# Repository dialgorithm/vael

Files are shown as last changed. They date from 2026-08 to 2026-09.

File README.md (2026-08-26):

<h1 align="center">
  vael
  <br>
</h1>

<h4 align="center">
esp32-s3 n8r8 flight controller for sensing and data logging.
</h4>

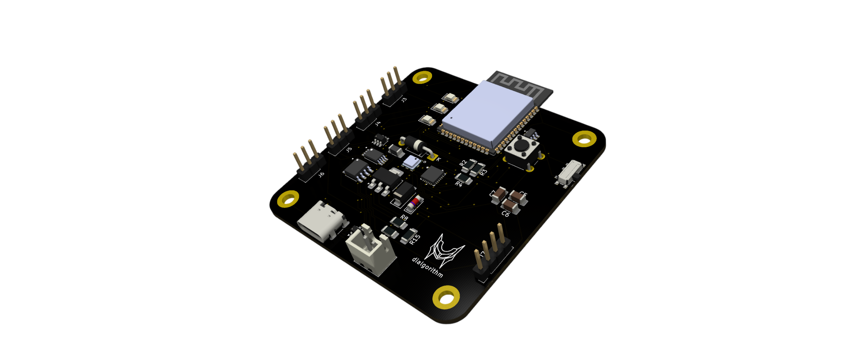
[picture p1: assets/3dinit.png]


## it features

- **ESP32-S3-WROOM-1-N8R8** as the main controller
- **MPU6050** 3-axis accelerometer and gyroscope for motion and orientation data
- **BMP180** digital pressure sensor for pressure and altitude-related measurements
- **MicroSD card storage** for flight data logging
- **USB-C connectivity** for programming, debugging, and data transfer
- **TP4056-based LiPo charging** circuitry
- **DW01A battery protection** for LiPo protection
- **MT3608 boost converter** for generating the required higher-voltage rail
- **AMS1117-3.3 LDO** for regulated 3.3 V power
- **USBLC6-2SC6 ESD protection** for USB protection

## design

**vael** is designed to keep the electronics compact while providing enough space for sensors, power circuitry, storage, and connectivity.

the board is built around the **esp32-s3-wroom-1-n8r8**, with the supporting electronics integrated onto a custom pcb. it combines the **imu, pressure sensor, microsd storage, usb-c interface, battery charging, protection, and voltage regulation** into a single compact board.

the layout keeps the sensing and processing electronics centralized while separating the power and signal sections. the **mpu6050** and **bmp180** are positioned for consistent sensor measurements, while the **microsd slot, usb-c connector, battery connector, reset button, and mode switch** are accessible from the board edges.

the board primarily uses **smd components**, including 1206 passives and compact sensor packages, to maintain a small form factor while providing the hardware required for **data collection, logging, and embedded flight applications**.

## Schematics + PCB

| Schematic | PCB | 3d |
| --- | --- | --- |
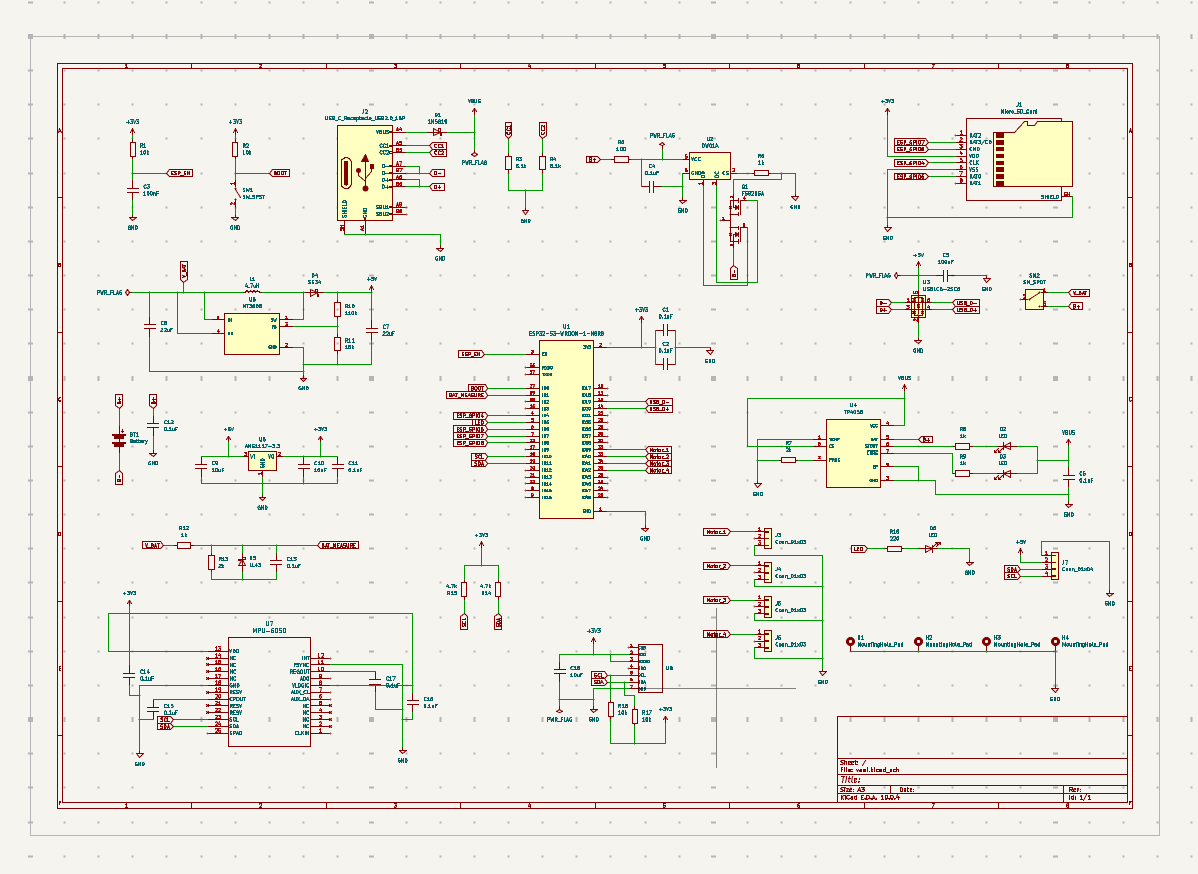
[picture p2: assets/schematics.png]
schematic
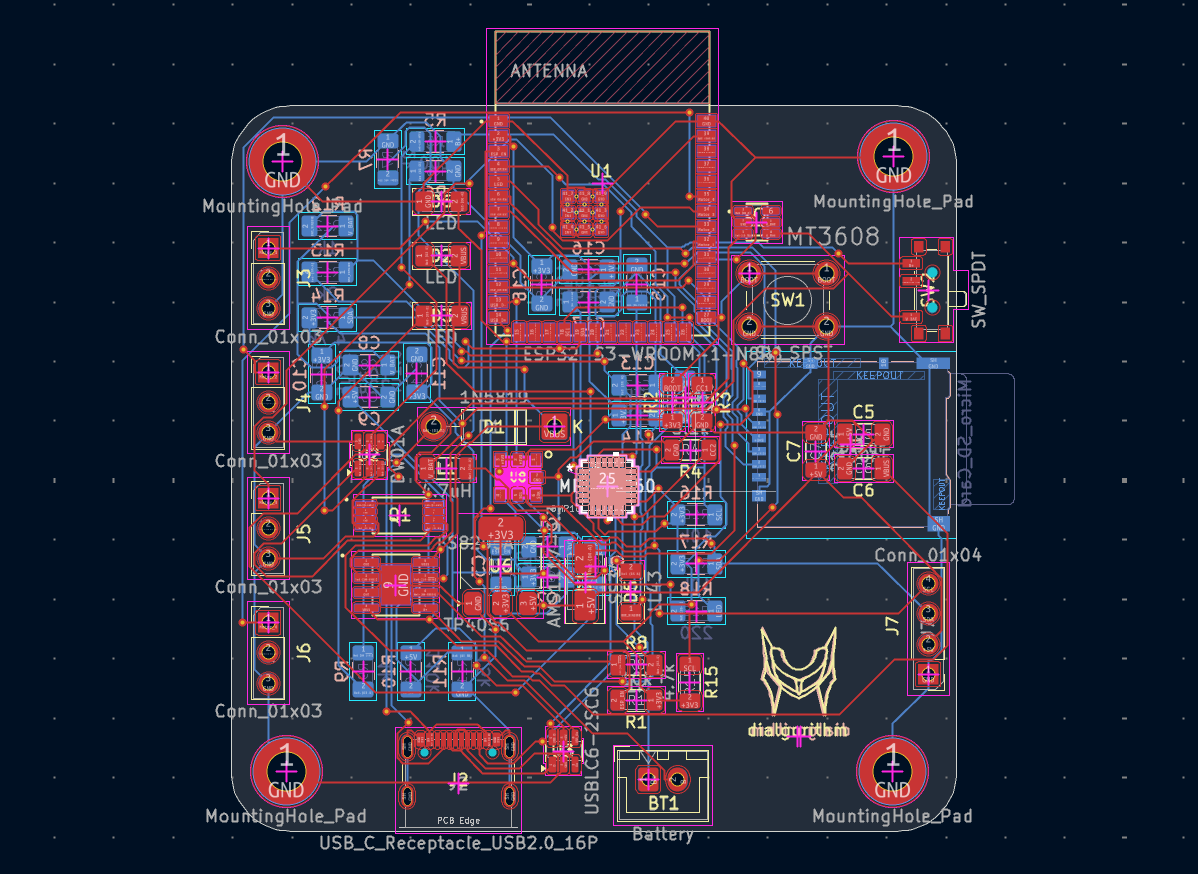
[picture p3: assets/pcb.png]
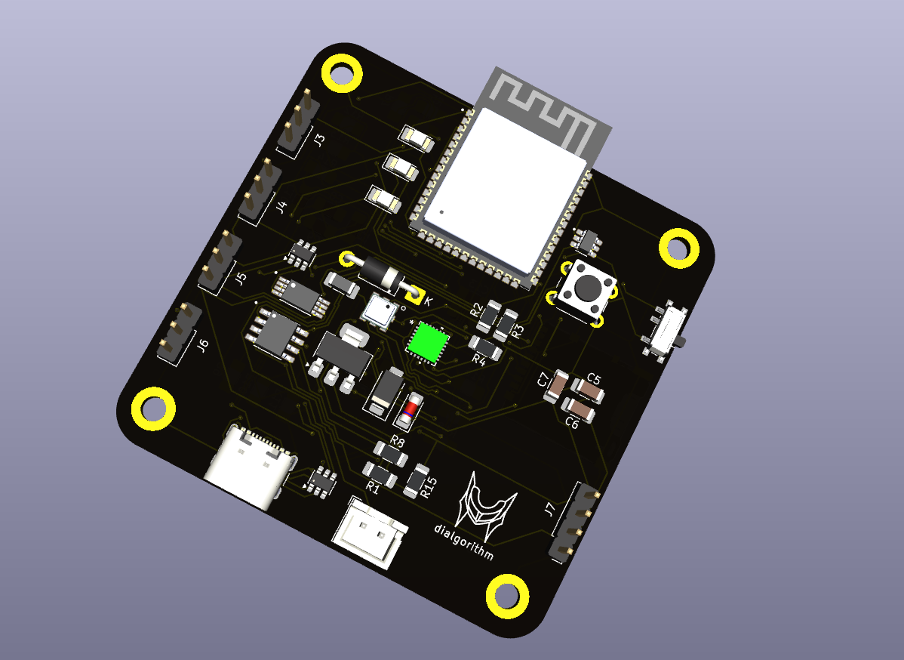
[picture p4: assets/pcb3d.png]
|  |  |  |

## BOM

the complete bill of materials is available in [`bom.csv`](bom.csv).

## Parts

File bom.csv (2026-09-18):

component | qty | cost | why | source
pcb | 5 | $13 | main | https://robu.in/product/online-pcb-manufacturing-service/
JST XH Pitch Plug and Socket | 2 | $0.5 | connect battery | https://robu.in/product/2-pin-jst-xh-2-54mm-pitch-plug-and-socket-with-cable-10-pcs/
0.1uF 1206 Capacitor | 22 | $1 | 11 per pcb | https://robu.in/product/0-1uf-capacitor-smdc-1206/
10uF 1206 Capacitor | 6 | $1.3 | 3 per pcb | https://robu.in/product/10uf-10000nf-50v-capacitor-1206-smd-package-pack-of-5/
100nF 1206 Capacitor | 5 | $0.5 | 2 per pcb | https://robu.in/product/100nf-1206-surface-mount-multilayer-ceramic-capacitor-pack-of-30/
22uF 1206 Capacitor | 5 | $0.5 | 2 per pcb | https://robu.in/product/1206x226m250nt-fh-25v-22uf-x5r%c2%b120-1206-multilayer-ceramic-capacitors-mlcc-smd-smt-rohs/
1N5819 Schottky Diodes | 2 | $0.9 | one way current flow | https://robu.in/product/1-month-warranty-1053/
LED 1206 Package | 6 | $0.8 | 3 per pcb | https://robu.in/product/xl-3216uoc-fb-xinglight-reverse-mount-orange-120-1206-led-indication-discrete-rohs/
SS34 Schottky Diodes ROHS | 2 | $2.3 | non reversible current | https://robu.in/product/ss34-onsemi-40v-500mv3a-3a-smcdo-214ab-schottky-diodes-rohs/
LL43-GS08 Rectifier Diode | 2 | $3 | no current backflow | https://www.lioncircuits.com/parts/LL43-GS08
DM3AT-SF-PEJM5 Micro SD socket | 2 | $13 | flight logs | https://www.lioncircuits.com/parts/DM3AT-SF-PEJM5
GCT USB4105 (USB C) Connector | 2 | $4 | flash and debug | https://www.lioncircuits.com/parts/USB4105-GF-A
2.54mm Male pin header | 10 | $3 | for motor connections | https://robu.in/product/2-54mm-1x40-pin-male-single-row-straight-short-header-strip-pack-of-3/
4.7uH 120p6 Inductor | 2 | $2.2 | for impedance | https://robu.in/product/lqm31pn4r7m00l-murata-electronics-700ma-4-7uh-%c2%b120-375m%cf%89-1206-inductors-smd-rohs/
FS8205A Mosfets | 5 | $1 |  | https://robu.in/product/1-month-warranty-398/
10k 1206 Resistors | 8 | $1 | 4 per pcb | https://robu.in/product/rc1206fr-0710kl-yageo-res-thick-film-1206-10k-ohm-1-0-25w1-4w-%c2%b1100ppm-c-pad-smd-t-r/
110k 1206 Resistors | 5 | $1 | resist current | https://robu.in/product/1206w4f1103t5e-uniohm-royal-ohm-250mw-thick-film-resistors-200v-%c2%b1100ppm-%e2%84%83%c2%b11-110k%cf%89-1206-chip-resistor-surface-mo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
15k 1206 Resistors | 5 | $1 | resist current | https://robu.in/product/1206w4f1502t5e-uniohm-royal-ohm-250mw-thick-film-resistors-200v-%c2%b1100ppm-%e2%84%83-%c2%b11-15k%cf%89-1206-chip-resistor-surface-mo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
1k 1206 Resistors | 8 | $1 | 4 per pcb | https://robu.in/product/wr12x1001ftl-walsin-250mw-thick-film-resistors-200v-%c2%b1100ppm-%e2%84%83-%c2%b11-1k%cf%89-1206-chip-resistor-surface-mount-rohs/
2k 1206 Resistors | 4 | $1 | 2 per pcb | https://robu.in/product/wr12x2001ftl-walsin-250mw-thick-film-resistors-200v-%c2%b1100ppm-%e2%84%83-%c2%b11-2k%cf%89-1206-chip-resistor-surface-mount-rohs/
4.7k 1206 Resistors | 4 | $1 | 2 per pcb | https://robu.in/product/rc1206fr-104k7l-yageo-250mw-thick-film-resistors-%c2%b1100ppm-%e2%84%83-%c2%b11-4-7k%cf%89-1206-chip-resistor-surface-mount-rohs/
220 1206 Resistors | 5 | $1 | resist current | https://robu.in/product/1206w4f2200t5e-uniohm-royal-ohm-250mw-thick-film-resistors-200v-%c2%b1100ppm-%e2%84%83%c2%b11-220%cf%89-1206-chip-resistor-surface-mou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
5.1k 1206 Resistors | 4 | $1 | 2 per pcb | https://robu.in/product/1206w4f5101t5e-uniohm-royal-ohm-250mw-thick-film-resistors-200v-%c2%b1100ppm-%e2%84%83-%c2%b11-5-1k%cf%89-1206-chip-resistor-surface-m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
100 1206 Resistors | 5 | $1 | resist current | https://robu.in/product/ac1206fr-07100rl-yageo-res-thick-film-1206-100-ohm-1-0-25w1-4w-%c2%b1100ppm-c-pad-smd-t-r-automotive-aec-q200/
6x6x5mm Tactile Push Button Switch | 2 | $1 | reset clicky | https://robu.in/product/6x6x5mm-tactile-push-button-switch-pack-of-20/
Mini Slide Switch 7Pin SMD | 2 | $1 | mode slide switch | https://sharvielectronics.com/product/mini-slide-switch-7pin-smd-2-positions-h1-5mm-1p2t-spdt/
ESP32-S3-WROOM-1-N8R8 | 2 | $13.8 | brain | https://robu.in/product/espressif-esp32-s3-wroom-1-n8r8-modules/
DW01A Battery Protection IC | 2 | $1 | protect pcb | https://robu.in/product/dw01a-4-3v-lithium-ion-lithium-polymer-battery-protection-ic-6pin-sot-23/
USBLC6-2SC6 ESD and Surge Protection IC | 2 | $1 | protect pcb | https://robu.in/product/usblc6-2sc6-ms-msksemi-4-5a-15v-150w-6v-5v-sot-23-6-esd-and-surge-protection-tvs-esd-rohs/
TP4056 SOP-8 SMD Package | 2 | $1 | battery charging | https://robu.in/product/1-month-warranty-1253/
MT3608 DC Boost converter | 2 | $1 | 3.3v ==> 5v | https://robu.in/product/mt3608-xian-aerosemi-tech-boost-type-adjustable-2a-2v24v-sot-23-6-dc-dc-converters-rohs/
AMS1117-3.3 LDO Regulators | 2 | $1 | regulates voltage | https://robu.in/product/1-month-warranty-385/
MPU 6050 QFN-24 3-Axis Gyro/Accelerometer IC | 2 | $11.6 | orientation and position data | https://zbotic.in/product/mpu-6050-qfn-24-3-axis-gyro-accelerometer-ic/
BMP180 LGA-7 Digital Pressure Sensor IC | 2 | $5.2 | pressure data | https://sharvielectronics.com/product/bmp180-digital-pressure-sensor-ic-lga-7-package/
8GB MicroSD Card | 2 | $8.4 | data logging | https://sharvielectronics.com/product/8gb-memory-card-sandisk/
Total | - | $110 | - | -

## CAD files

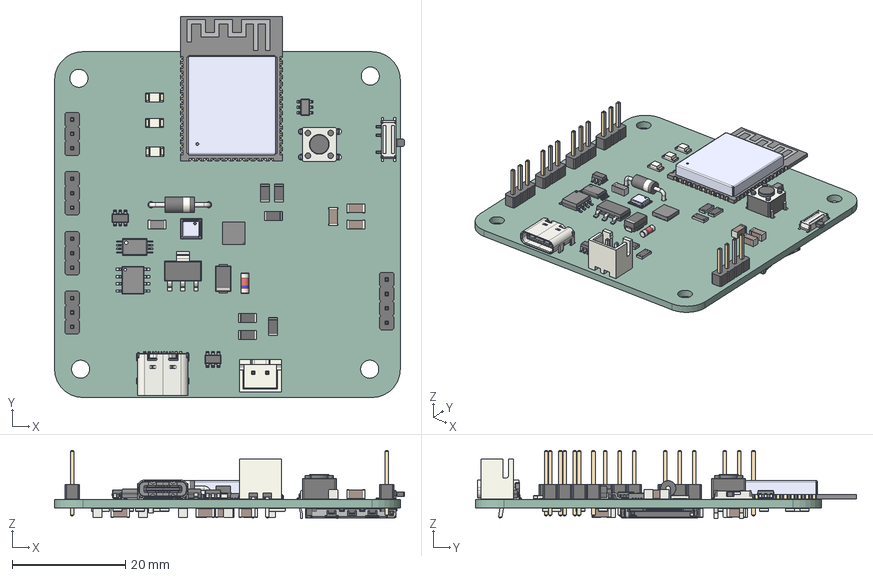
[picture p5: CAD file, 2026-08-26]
KiCAD/vael.step
61.7 x 67.2 x 12.0 mm
MT3608
ICM-20689
R_1206_3216Metric x 18
D_SMA
C_1206_3216Metric x 18
D_DO-41_SOD81_P10.16mm_Horizontal
SOT-223
LED_1206_3216Metric x 3
BMP180
JST_B2B_XH_A
SOT-23-6 x 2
PinHeader_1x04_P254mm_Vertical
ESP32-S3-WROOM-1-N8R2
FS8205A
L_1206_3216Metric
SW_PUSH_6mm
D_MiniMELF_Standard
TP4056
PinHeader_1x03_P254mm_Vertical x 4
Fusion_sp
USB_C_Receptacle_16P_TopMnt_Horizontal_GCT_USB4105-xx-A
microSD_HC_Hirose_DM3AT-SF-PEJM5
vael_PCB

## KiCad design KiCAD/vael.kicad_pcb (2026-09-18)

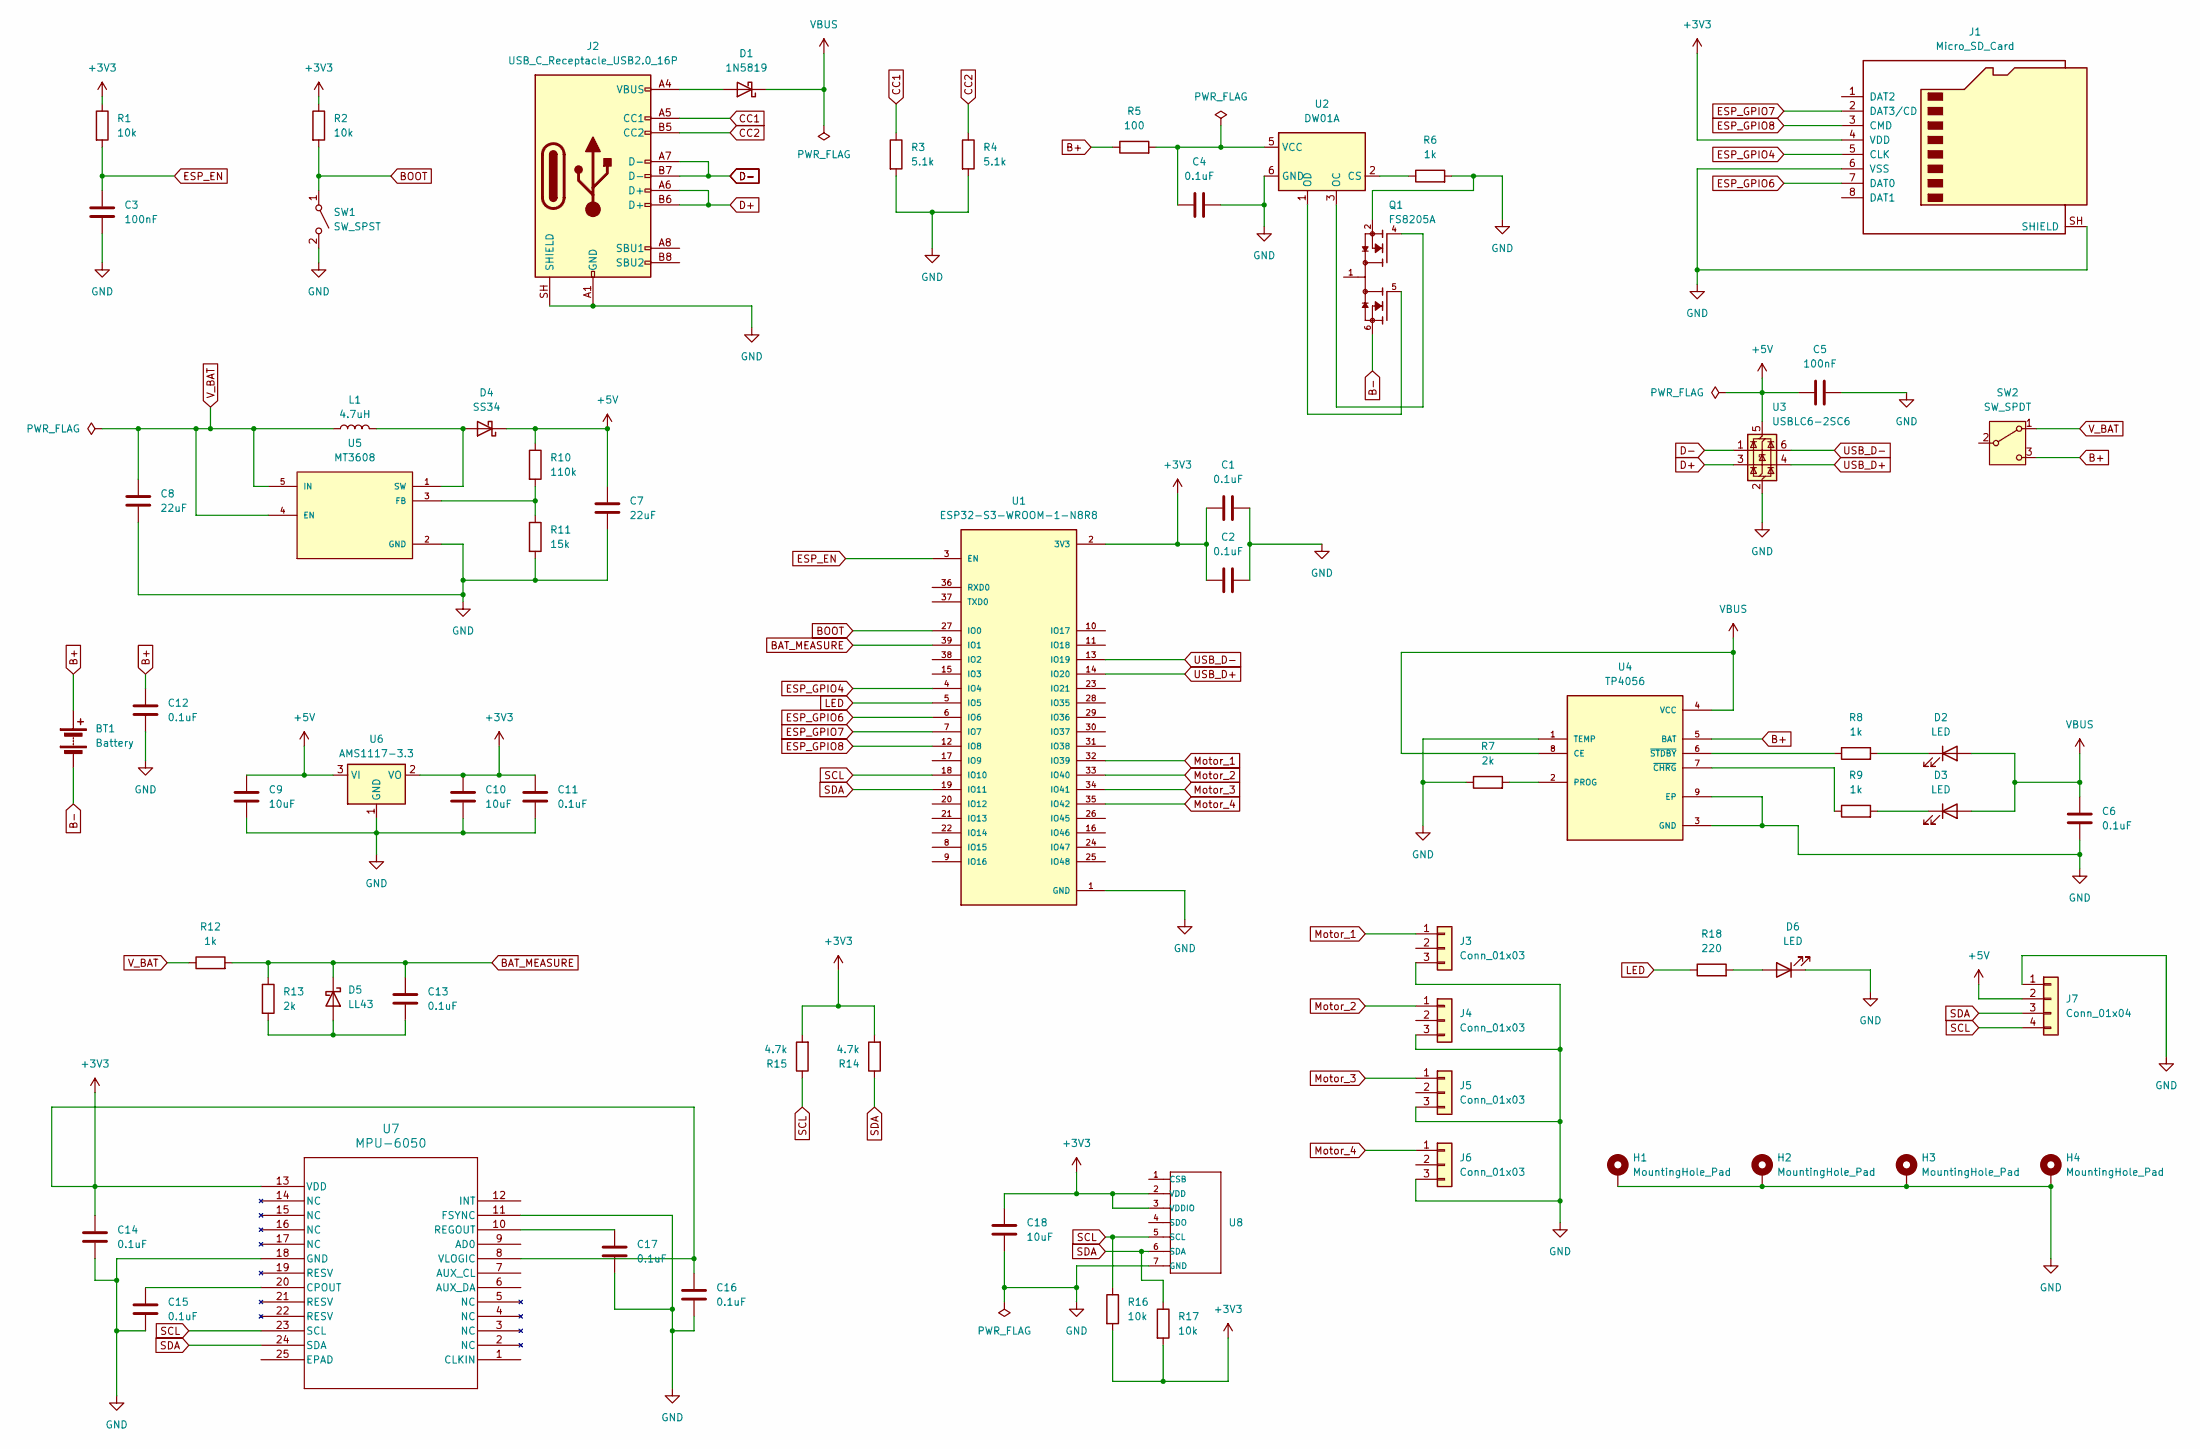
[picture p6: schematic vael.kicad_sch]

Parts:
BT1: Battery; JST_XH_B2B-XH-A_1x02_P2.50mm_Vertical
C1, C2, C4, C6, C11, C12, C13, C14, C15, C16, C17: 0.1uF; C_1206_3216Metric_Pad1.33x1.80mm_HandSolder
C3, C5: 100nF; C_1206_3216Metric_Pad1.33x1.80mm_HandSolder
C7, C8: 22uF; C_1206_3216Metric_Pad1.33x1.80mm_HandSolder
C9, C10, C18: 10uF; C_1206_3216Metric_Pad1.33x1.80mm_HandSolder
D1: 1N5819; D_DO-41_SOD81_P10.16mm_Horizontal
D2, D3, D6: LED; LED_1206_3216Metric_Pad1.42x1.75mm_HandSolder
D4: SS34; D_SMA
D5: LL43; D_MiniMELF
H1, H2, H3, H4: MountingHole_Pad; MountingHole_3.2mm_M3_DIN965_Pad
J1: Micro_SD_Card; microSD_HC_Hirose_DM3AT-SF-PEJM5
J2: USB_C_Receptacle_USB2.0_16P; USB_C_Receptacle_GCT_USB4105-xx-A_16P_TopMnt_Horizontal
J3, J4, J5, J6: Conn_01x03; PinHeader_1x03_P2.54mm_Vertical
J7: Conn_01x04; PinHeader_1x04_P2.54mm_Vertical
L1: 4.7uH; L_1206_3216Metric_Pad1.22x1.90mm_HandSolder
Q1: FS8205A; SOP65P640X120-8N; PARTREV 1.7
R1, R2, R16, R17: 10k; R_1206_3216Metric_Pad1.30x1.75mm_HandSolder
R3, R4: 5.1k; R_1206_3216Metric_Pad1.30x1.75mm_HandSolder
R5: 100; R_1206_3216Metric_Pad1.30x1.75mm_HandSolder
R6, R8, R9, R12: 1k; R_1206_3216Metric_Pad1.30x1.75mm_HandSolder
R7, R13: 2k; R_1206_3216Metric_Pad1.30x1.75mm_HandSolder
R10: 110k; R_1206_3216Metric_Pad1.30x1.75mm_HandSolder
R11: 15k; R_1206_3216Metric_Pad1.30x1.75mm_HandSolder
R14, R15: 4.7k; R_1206_3216Metric_Pad1.30x1.75mm_HandSolder
R18: 220; R_1206_3216Metric_Pad1.30x1.75mm_HandSolder
SW1: SW_SPST; SW_PUSH_6mm
SW2: SW_SPDT; SW_SPDT_PCM12
U1: ESP32-S3-WROOM-1-N8R8; XCVR_ESP32S3WROOM1N8R8
U2: DW01A; SOT-23-6
U3: USBLC6-2SC6; SOT-23-6
U4: TP4056; SOP127P600X175-9N
U5: MT3608; SOT95P280X145-6N; PARTREV 1.0
U6: AMS1117-3.3; SOT-223-3_TabPin2
U7: MPU-6050; QFN24_4X4X0P9-0P5_TDK
U8: BMP18; LGA7-1.5-3.8X3.6MM; MPN BMP18

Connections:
+3V3: C1.1, C2.1, C10.1, C11.1, C14.1, C16.1, C18.1, J1.4 (VDD), R1.1, R2.1, R14.2, R15.2, R16.2, R17.2, U1.2 (3V3), U6.2 (VO), U7.8 (VLOGIC), U7.13 (VDD), U8.2 (VDD), U8.3 (VDDIO)
+5V: C5.1, C7.1, C9.1, D4.1 (K), J7.2, R10.1, U3.5 (VBUS), U6.3 (VI)
B+: BT1.1 (+), C12.1, R5.1, SW2.3 (C), U4.5 (BAT)
B-: BT1.2 (-), Q1.6, Q1.7
BAT_MEASURE: C13.1, D5.1 (K), R12.2, R13.1, U1.39 (IO1)
BOOT: R2.2, SW1.1 (A), U1.27 (IO0)
CC1: J2.A5 (CC1), R3.1
CC2: J2.B5 (CC2), R4.1
D+: J2.A6 (D+), J2.B6 (D+), U3.3 (I/O2)
D-: J2.A7 (D-), J2.B7 (D-), U3.1 (I/O1)
ESP_EN: C3.1, R1.2, U1.3 (EN)
ESP_GPIO4: J1.5 (CLK), U1.4 (IO4)
ESP_GPIO6: J1.7 (DAT0), U1.6 (IO6)
ESP_GPIO7: J1.2 (DAT3/CD), U1.7 (IO7)
ESP_GPIO8: J1.3 (CMD), U1.12 (IO8)
GND: C1.2, C2.2, C3.2, C4.2, C5.2, C6.2, C7.2, C8.2, C9.2, C10.2, C11.2, C12.2, C14.2, C15.2, C16.2, C17.2, C18.2, D6.1 (K), H1.1 (1_1), H2.1 (1_1), H3.1 (1_1), H4.1 (1_1), J1.6 (VSS), J1.SH (SHIELD), J2.A1 (GND), J2.A12 (GND), J2.B1 (GND), J2.B12 (GND), J2.SH (SHIELD), J3.3, J4.3, J5.3, J6.3, J7.1, Q1.2, Q1.3, R3.2, R4.2, R6.2, R7.1, R11.2, SW1.2 (B), U1.1 (GND), U1.40 (GND), U1.41_1 (GND), U1.41_2 (GND), U1.41_3 (GND), U1.41_4 (GND), U1.41_5 (GND), U1.41_6 (GND), U1.41_7 (GND), U1.41_8 (GND), U1.41_9 (GND), U2.6 (GND), U3.2 (GND), U4.1 (TEMP), U4.3 (GND), U4.9 (EP), U5.2 (GND), U6.1 (GND), U7.11 (FSYNC), U7.18 (GND), U8.7 (GND)
LED: R18.1, U1.5 (IO5)
Motor_1: J3.1, U1.32 (IO39)
Motor_2: J4.1, U1.33 (IO40)
Motor_3: J5.1, U1.34 (IO41)
Motor_4: J6.1, U1.35 (IO42)
unnamed: D1.2 (A), J2.A4 (VBUS), J2.A9 (VBUS), J2.B4 (VBUS), J2.B9 (VBUS)
unnamed: D2.1 (K), R8.2
unnamed: D3.1 (K), R9.2
unnamed: D4.2 (A), L1.2, U5.1 (SW)
unnamed: C13.2, D5.2 (A), R13.2
unnamed: D6.2 (A), R18.2
unnamed: Q1.1, Q1.8
unnamed: R6.1, U2.2 (CS)
unnamed: Q1.4, U2.3 (OC)
unnamed: Q1.5, U2.1 (OD)
unnamed: C4.1, R5.2, U2.5 (VCC)
unnamed: R7.2, U4.2 (PROG)
unnamed: R9.1, U4.7 (~CHRG)
unnamed: R8.1, U4.6 (~STDBY)
unnamed: R10.2, R11.1, U5.3 (FB)
unnamed: C15.1, U7.20 (CPOUT)
unnamed: C17.1, U7.10 (REGOUT)
SCL: J7.4, R15.1, R16.1, U1.18 (IO10), U7.23 (SCL), U8.5 (SCL)
SDA: J7.3, R14.1, R17.1, U1.19 (IO11), U7.24 (SDA), U8.6 (SDA)
USB_D+: U1.14 (IO20), U3.4 (I/O2)
USB_D-: U1.13 (IO19), U3.6 (I/O1)
VBUS: C6.1, D1.1 (K), D2.2 (A), D3.2 (A), U4.4 (VCC), U4.8 (CE)
V_BAT: C8.1, L1.1, R12.1, SW2.1 (A), U5.4 (EN), U5.5 (IN)

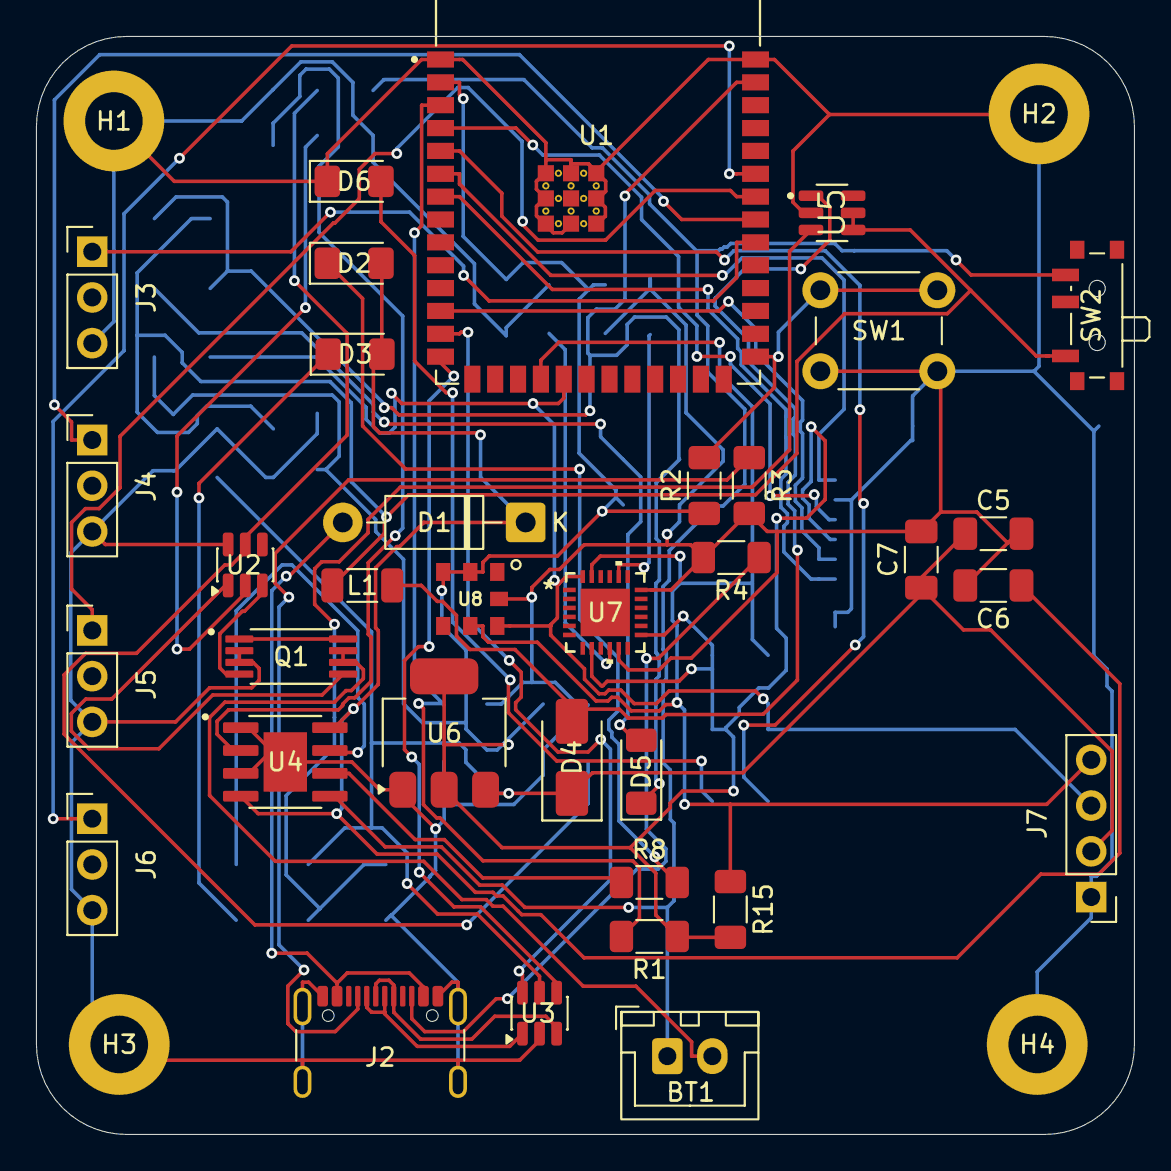
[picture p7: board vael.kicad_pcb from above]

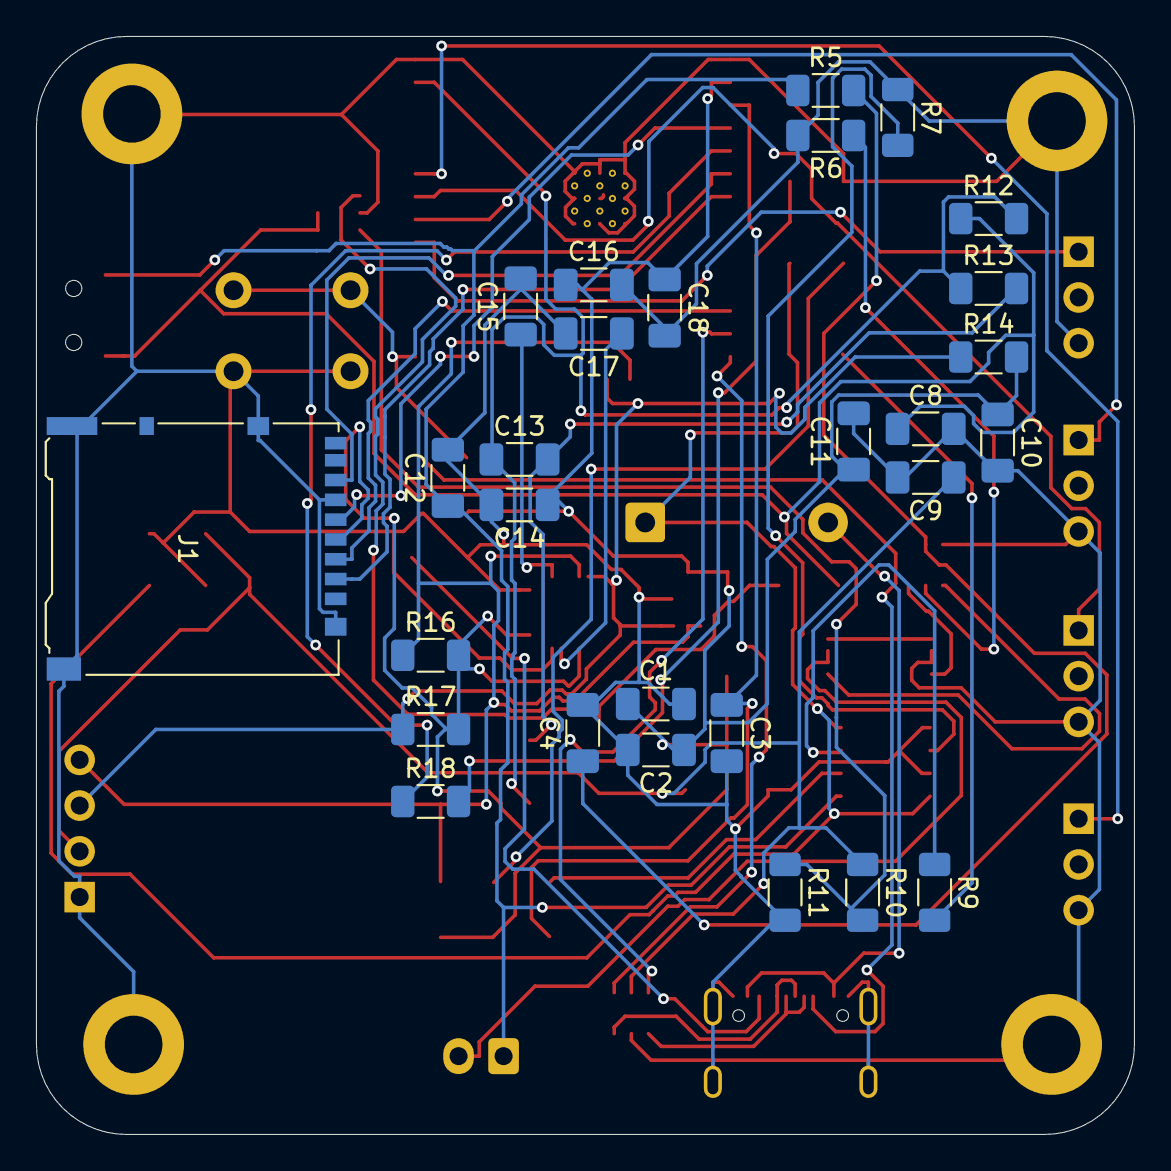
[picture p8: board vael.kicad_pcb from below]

Board: 2 copper layers, 61.0 x 61.0 mm, 66 parts (28 on the bottom side), 44 nets.

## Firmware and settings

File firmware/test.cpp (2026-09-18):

#include <Arduino.h>
#include <Wire.h>
#include <SPI.h>
#include <SD.h>
#include <Adafruit_MPU6050.h>
#include <Adafruit_BMP085.h>

// ============================================================
// VAEL - ESP32-S3 BASIC FLIGHT CONTROLLER FIRMWARE
//
// Arduino ESP32 core
//
// Functions:
//   - ELRS / CRSF RC receiver
//   - RC failsafe
//   - Arm/disarm
//   - MPU6050
//   - BMP180
//   - MicroSD logging
//   - Four PWM output channels
//
// IMPORTANT:
// This firmware is NOT a flight-ready stabilization controller.
// Do not connect propellers during initial testing.
// ============================================================


// ============================================================
// PIN CONFIGURATION
// ============================================================

// I2C
#define I2C_SDA             8
#define I2C_SCL             9

// ELRS receiver UART
#define ELRS_RX_PIN         18
#define ELRS_TX_PIN         17

// microSD SPI
#define SD_SCK_PIN          12
#define SD_MISO_PIN         13
#define SD_MOSI_PIN         11
#define SD_CS_PIN           10

// Motor / actuator outputs
#define MOTOR_1_PIN         4
#define MOTOR_2_PIN         5
#define MOTOR_3_PIN         6
#define MOTOR_4_PIN         7


// ============================================================
// RC CONFIGURATION
// ============================================================

#define RC_CHANNELS         16

// Typical CRSF channel indexes
#define CH_ROLL             0
#define CH_PITCH            1
#define CH_THROTTLE         2
#define CH_YAW              3

// Change this to match your ELRS transmitter.
// Example: channel 4 used as ARM switch.
#define CH_ARM              4

// CRSF nominal channel range
#define RC_MIN              172
#define RC_MID              992
#define RC_MAX              1811

// Receiver considered lost after this interval
#define RC_TIMEOUT_MS       250


// ============================================================
// PWM CONFIGURATION
// ============================================================

#define PWM_FREQUENCY       400
#define PWM_RESOLUTION      12

#define PWM_MIN             1000
#define PWM_MAX             2000

#define MOTOR_IDLE          1000


// ============================================================
// GLOBAL OBJECTS
// ============================================================

HardwareSerial ELRS(1);

Adafruit_MPU6050 mpu;
Adafruit_BMP085 bmp;

bool mpuOK = false;
bool bmpOK = false;
bool sdOK  = false;


// ============================================================
// RC STATE
// ============================================================

uint16_t rcChannels[RC_CHANNELS];

bool receiverConnected = false;
bool armed = false;

uint32_t lastRCFrame = 0;


// ============================================================
// CRSF
// ============================================================

#define CRSF_ADDRESS_FLIGHT_CONTROLLER 0xC8
#define CRSF_FRAMETYPE_RC_CHANNELS     0x16

uint8_t crsfBuffer[64];
uint8_t crsfIndex = 0;
uint8_t crsfLength = 0;


// ============================================================
// LOGGING
// ============================================================

File logFile;

uint32_t lastLogTime = 0;
uint32_t logStartTime = 0;


// ============================================================
// SENSOR VALUES
// ============================================================

float accelX = 0;
float accelY = 0;
float accelZ = 0;

float gyroX = 0;
float gyroY = 0;
float gyroZ = 0;

float temperature = 0;
float pressure = 0;
float altitude = 0;


// ============================================================
// MOTOR VALUES
// ============================================================

uint16_t motor1 = MOTOR_IDLE;
uint16_t motor2 = MOTOR_IDLE;
uint16_t motor3 = MOTOR_IDLE;
uint16_t motor4 = MOTOR_IDLE;


// ============================================================
// CRSF CRC8
// ============================================================

uint8_t crc8(const uint8_t *ptr, uint8_t len)
{
    uint8_t crc = 0;

    while (len--)
    {
        crc ^= *ptr++;

        for (uint8_t i = 0; i < 8; i++)
        {
            if (crc & 0x80)
                crc = (crc << 1) ^ 0xD5;
            else
                crc <<= 1;
        }
    }

    return crc;
}


// ============================================================
// CRSF CHANNEL DECODER
// ============================================================

void decodeCRSFChannels(uint8_t *payload)
{
    // CRSF packs 16 channels as 11-bit values.

    uint32_t bits = 0;
    uint8_t bitCount = 0;

    uint8_t channel = 0;

    for (uint8_t i = 0; i < 22 && channel < RC_CHANNELS; i++)
    {
        bits |= ((uint32_t)payload[i]) << bitCount;
        bitCount += 8;

        while (bitCount >= 11 && channel < RC_CHANNELS)
        {
            rcChannels[channel] = bits & 0x07FF;

            bits >>= 11;
            bitCount -= 11;

            channel++;
        }
    }

    receiverConnected = true;
    lastRCFrame = millis();
}


// ============================================================
// CRSF PARSER
// ============================================================

void processCRSF()
{
    while (ELRS.available())
    {
        uint8_t b = ELRS.read();

        // First byte = device address
        if (crsfIndex == 0)
        {
            if (b != CRSF_ADDRESS_FLIGHT_CONTROLLER)
                continue;

            crsfBuffer[crsfIndex++] = b;
            continue;
        }

        // Second byte = frame length
        if (crsfIndex == 1)
        {
            crsfLength = b;

            if (crsfLength < 2 || crsfLength > 62)
            {
                crsfIndex = 0;
                continue;
            }

            crsfBuffer[crsfIndex++] = b;
            continue;
        }

        crsfBuffer[crsfIndex++] = b;

        // frame = address + length + payload + CRC
        if (crsfIndex >= crsfLength + 2)
        {
            uint8_t type = crsfBuffer[2];

            uint8_t crcReceived =
                crsfBuffer[crsfIndex - 1];

            uint8_t crcCalculated =
                crc8(&crsfBuffer[2], crsfLength - 1);

            if (crcReceived == crcCalculated)
            {
                if (type == CRSF_FRAMETYPE_RC_CHANNELS)
                {
                    // RC channels occupy bytes 3-24
                    decodeCRSFChannels(&crsfBuffer[3]);
                }
            }

            crsfIndex = 0;
        }
    }
}


// ============================================================
// RC HELPERS
// ============================================================

float rcToNormalized(uint16_t value)
{
    float x = ((float)value - RC_MID) /
              ((float)RC_MAX - RC_MIN) * 2.0f;

    return constrain(x, -1.0f, 1.0f);
}


float rcThrottle()
{
    float t =
        ((float)rcChannels[CH_THROTTLE] - RC_MIN) /
        ((float)RC_MAX - RC_MIN);

    return constrain(t, 0.0f, 1.0f);
}


bool armSwitchActive()
{
    return rcChannels[CH_ARM] > 1500;
}


// ============================================================
// FAILSAFE
// ============================================================

bool rcFailsafe()
{
    if (!receiverConnected)
        return true;

    if (millis() - lastRCFrame > RC_TIMEOUT_MS)
        return true;

    return false;
}


// ============================================================
// ARMING
// ============================================================

void updateArming()
{
    if (rcFailsafe())
    {
        armed = false;
        return;
    }

    // Require low throttle before arming.
    bool throttleLow = rcThrottle() < 0.05f;

    if (!armed)
    {
        if (armSwitchActive() && throttleLow)
        {
            armed = true;
        }
    }
    else
    {
        if (!armSwitchActive())
        {
            armed = false;
        }
    }
}


// ============================================================
// MOTOR OUTPUT
// ============================================================
//
// This function deliberately does NOT implement a flight
// controller. It provides a controlled output interface.
//
// Until stabilization/mixer code is added, outputs remain at
// minimum when disarmed.
//
// This prevents raw transmitter commands from directly
// driving motors during initial hardware testing.
//

void writeMotor(uint8_t pin, uint16_t us)
{
    us = constrain(us, PWM_MIN, PWM_MAX);

    // 400 Hz PWM:
    //
    // period = 2500 us
    //
    // 12-bit duty:
    // duty = pulse / 2500 * 4095

    uint32_t duty =
        ((uint32_t)us * 4095UL) / 2500UL;

    ledcWrite(pin, duty);
}


void updateMotors()
{
    if (!armed || rcFailsafe())
    {
        motor1 = MOTOR_IDLE;
        motor2 = MOTOR_IDLE;
        motor3 = MOTOR_IDLE;
        motor4 = MOTOR_IDLE;
    }
    else
    {
        // ----------------------------------------------------
        // BENCH OUTPUT MODE
        //
        // Throttle is mapped to all four outputs equally.
        //
        // This is NOT a quadcopter mixer or stabilization loop.
        // ----------------------------------------------------

        uint16_t throttle =
            PWM_MIN +
            rcThrottle() * (PWM_MAX - PWM_MIN);

        motor1 = throttle;
        motor2 = throttle;
        motor3 = throttle;
        motor4 = throttle;
    }

    writeMotor(MOTOR_1_PIN, motor1);
    writeMotor(MOTOR_2_PIN, motor2);
    writeMotor(MOTOR_3_PIN, motor3);
    writeMotor(MOTOR_4_PIN, motor4);
}


// ============================================================
// MPU6050
// ============================================================

void readMPU6050()
{
    if (!mpuOK)
        return;

    sensors_event_t accel;
    sensors_event_t gyro;
    sensors_event_t temp;

    mpu.getEvent(&accel, &gyro, &temp);

    accelX = accel.acceleration.x;
    accelY = accel.acceleration.y;
    accelZ = accel.acceleration.z;

    gyroX = gyro.gyro.x;
    gyroY = gyro.gyro.y;
    gyroZ = gyro.gyro.z;

    temperature = temp.temperature;
}


// ============================================================
// BMP180
// ============================================================

void readBMP180()
{
    if (!bmpOK)
        return;

    pressure = bmp.readPressure();

    altitude =
        bmp.readAltitude(101325.0);
}


// ============================================================
// SD LOGGING
// ============================================================

void startLogging()
{
    if (!sdOK)
        return;

    String filename = "/flight.csv";

    logFile = SD.open(filename, FILE_APPEND);

    if (!logFile)
        return;

    // Write header if file is empty.
    if (logFile.size() == 0)
    {
        logFile.println(
            "time_ms,"
            "armed,"
            "failsafe,"
            "ch1,"
            "ch2,"
            "ch3,"
            "ch4,"
            "accel_x,"
            "accel_y,"
            "accel_z,"
            "gyro_x,"
            "gyro_y,"
            "gyro_z,"
            "pressure,"
            "altitude,"
            "motor1,"
            "motor2,"
            "motor3,"
            "motor4"
        );

        logFile.flush();
    }

    logStartTime = millis();
}


void logData()
{
    if (!sdOK || !logFile)
        return;

    if (millis() - lastLogTime < 20)
        return;

    lastLogTime = millis();

    logFile.print(millis());
    logFile.print(",");

    logFile.print(armed);
    logFile.print(",");

    logFile.print(rcFailsafe());
    logFile.print(",");

    for (int i = 0; i < 4; i++)
    {
        logFile.print(rcChannels[i]);
        logFile.print(",");
    }

    logFile.print(accelX, 4);
    logFile.print(",");

    logFile.print(accelY, 4);
    logFile.print(",");

    logFile.print(accelZ, 4);
    logFile.print(",");

    logFile.print(gyroX, 4);
    logFile.print(",");

    logFile.print(gyroY, 4);
    logFile.print(",");

    logFile.print(gyroZ, 4);
    logFile.print(",");

    logFile.print(pressure, 2);
    logFile.print(",");

    logFile.print(altitude, 2);
    logFile.print(",");

    logFile.print(motor1);
    logFile.print(",");

    logFile.print(motor2);
    logFile.print(",");

    logFile.print(motor3);
    logFile.print(",");

    logFile.println(motor4);

    // Don't flush every line.
    // Flush periodically for better SD performance.
    static uint32_t lastFlush = 0;

    if (millis() - lastFlush > 1000)
    {
        logFile.flush();
        lastFlush = millis();
    }
}


// ============================================================
// SERIAL DEBUG
// ============================================================

void printStatus()
{
    static uint32_t lastPrint = 0;

    if (millis() - lastPrint < 500)
        return;

    lastPrint = millis();

    Serial.print("RC: ");

    for (int i = 0; i < 6; i++)
    {
        Serial.print(rcChannels[i]);
        Serial.print(" ");
    }

    Serial.print("| ARM=");
    Serial.print(armed);

    Serial.print(" FS=");
    Serial.print(rcFailsafe());

    Serial.print(" | ACC=");
    Serial.print(accelX, 2);
    Serial.print(",");
    Serial.print(accelY, 2);
    Serial.print(",");
    Serial.print(accelZ, 2);

    Serial.print(" | ALT=");
    Serial.print(altitude, 2);

    Serial.print(" | MOT=");
    Serial.print(motor1);
    Serial.print(",");
    Serial.print(motor2);
    Serial.print(",");
    Serial.print(motor3);
    Serial.print(",");
    Serial.println(motor4);
}


// ============================================================
// SETUP
// ============================================================

void setup()
{
    Serial.begin(115200);

    delay(1000);

    Serial.println();
    Serial.println("================================");
    Serial.println("VAEL FLIGHT CONTROLLER");
    Serial.println("ESP32-S3");
    Serial.println("================================");

    // --------------------------------------------------------
    // I2C
    // --------------------------------------------------------

    Wire.begin(I2C_SDA, I2C_SCL);

    // --------------------------------------------------------
    // MPU6050
    // --------------------------------------------------------

    if (mpu.begin(0x68, &Wire))
    {
        mpuOK = true;

        mpu.setAccelerometerRange(
            MPU6050_RANGE_8_G
        );

        mpu.setGyroRange(
            MPU6050_RANGE_500_DEG
        );

        mpu.setFilterBandwidth(
            MPU6050_BAND_44_HZ
        );

        Serial.println("MPU6050: OK");
    }
    else
    {
        Serial.println("MPU6050: FAIL");
    }

    // --------------------------------------------------------
    // BMP180
    // --------------------------------------------------------

    if (bmp.begin())
    {
        bmpOK = true;
        Serial.println("BMP180: OK");
    }
    else
    {
        Serial.println("BMP180: FAIL");
    }

    // --------------------------------------------------------
    // ELRS / CRSF
    // --------------------------------------------------------

    //
    // CRSF is normally:
    //
    // ELRS TX -> ESP32 RX
    // ELRS RX -> ESP32 TX
    // GND     -> GND
    //
    // Many ELRS receivers only require TX -> FC RX
    // for RC input.
    //

    ELRS.begin(
        420000,
        SERIAL_8N1,
        ELRS_RX_PIN,
        ELRS_TX_PIN
    );

    Serial.println("ELRS UART: started");

    // --------------------------------------------------------
    // PWM
    // --------------------------------------------------------

    ledcAttach(
        MOTOR_1_PIN,
        PWM_FREQUENCY,
        PWM_RESOLUTION
    );

    ledcAttach(
        MOTOR_2_PIN,
        PWM_FREQUENCY,
        PWM_RESOLUTION
    );

    ledcAttach(
        MOTOR_3_PIN,
        PWM_FREQUENCY,
        PWM_RESOLUTION
    );

    ledcAttach(
        MOTOR_4_PIN,
        PWM_FREQUENCY,
        PWM_RESOLUTION
    );

    // Always start outputs at minimum.
    writeMotor(MOTOR_1_PIN, MOTOR_IDLE);
    writeMotor(MOTOR_2_PIN, MOTOR_IDLE);
    writeMotor(MOTOR_3_PIN, MOTOR_IDLE);
    writeMotor(MOTOR_4_PIN, MOTOR_IDLE);

    // --------------------------------------------------------
    // SD
    // --------------------------------------------------------

    SPI.begin(
        SD_SCK_PIN,
        SD_MISO_PIN,
        SD_MOSI_PIN,
        SD_CS_PIN
    );

    if (SD.begin(SD_CS_PIN, SPI))
    {
        sdOK = true;
        Serial.println("microSD: OK");

        startLogging();
    }
    else
    {
        Serial.println("microSD: FAIL");
    }

    // --------------------------------------------------------
    // Initialize RC
    // --------------------------------------------------------

    for (int i = 0; i < RC_CHANNELS; i++)
        rcChannels[i] = RC_MID;

    rcChannels[CH_THROTTLE] = RC_MIN;

    Serial.println("VAEL initialization complete.");
}


// ============================================================
// LOOP
// ============================================================

void loop()
{
    // Highest priority: receive RC data.
    processCRSF();

    // Read sensors.
    readMPU6050();
    readBMP180();

    // Update arm/failsafe state.
    updateArming();

    // Update outputs.
    updateMotors();

    // Record flight data.
    logData();

    // USB serial diagnostics.
    printStatus();

    delay(1);
}

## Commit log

2026-08-26 bom + readme
    [bom.csv]
2026-09-18 test firmware
    [bom.csv, vael.kicad_pcb]
